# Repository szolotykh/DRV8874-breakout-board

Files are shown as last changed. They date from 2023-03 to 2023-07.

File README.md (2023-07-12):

# Motor Controller DRV8874

The Motor Controller, harnessing the power of the DRV8874 H-bridge motor driver by Texas Instruments, offers a top-of-the-line solution for managing small to large DC motors. This compact yet potent device presents an expansive operating supply voltage range of 4.5V to 37V, assuring adaptability with diverse power inputs. It is capable of delivering a peak current of up to a remarkable 6A, ensuring smooth and efficient motor operations even under strenuous conditions. Armed with advanced safety and protection features including overcurrent, thermal, undervoltage, and even charge pump undervoltage, the motor controller prioritizes your motor's durability and reliable performance. Whether your project involves creating a versatile home appliance, an interactive toy robot, or an advanced servo motor system, this motor controller delivers effortless integration and superior performance, empowering your projects with precision and power.

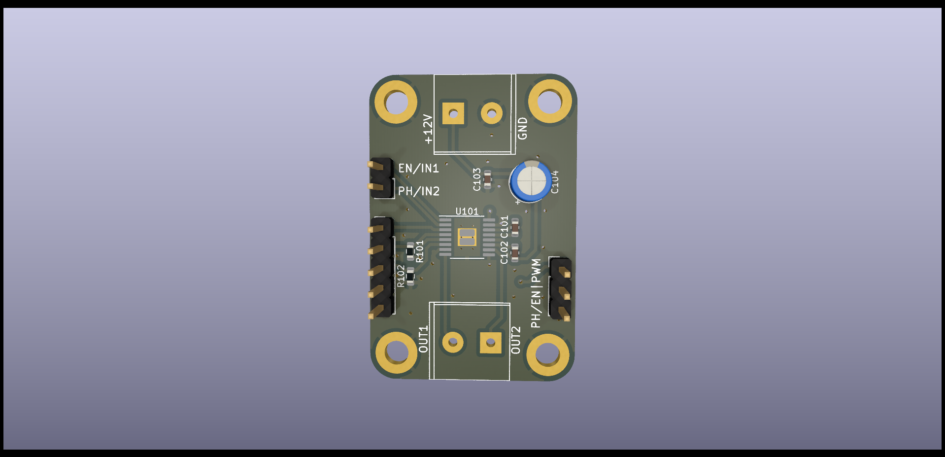
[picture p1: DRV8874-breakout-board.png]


## Features
- PWM control
- PH/EN control
- Motor Voltage 4.5V to 37V
- Peak current 6A
- Current limit 6A
- PWM frequency upto 100 kHz
- 200-mΩ (High-Side + Low-Side)
- Dimensions 27 mm x 40 mm
- Mounting hole diameter 3.2 mm
- Integrated current sensing and regulation
- Undervoltage lockout
- Charge pump undervoltage
- Overcurrent protection
- Thermal shutdown
- Automatic fault recovery
- Fault indicator pin (nFAULT)
Note: For more information refer to DRV8874 datasheet.

## Control Modes

The DRV8874 Breakout Board supports two different control modes: PH/EN and PWM. The PH/EN mode uses the PH and EN pins to control the motor, while the PWM mode uses the IN1 and IN2 pins and PWM signals to control the motor.

To switch between the control modes, you need to change the position of the "PH/EN|PWM" jumper on the board. When the jumper is in the PH/EN position, the board is in PH/EN mode. When the jumper is in the PWM position, the board is in PWM mode.

## Arduino Examples

* [PWM Control](./exampes/PWMControl/PWMControl.ino)
* [PH/EN Control](./exampes/PHENControl/PHENControl.ino)
* [Current Sensing](./exampes/CurrentSensing/CurrentSensing.ino)

## Resources

- [Texas Instruments DRV8874](https://www.ti.com/lit/ds/symlink/drv8874.pdf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)

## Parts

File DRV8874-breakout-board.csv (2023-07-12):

Reference | Value | Footprint | LCSC Part # | Qty
C101 | 22nf | Capacitor_SMD:C_0603_1608Metric | C277528 | 1
C102, C103 | 0.1uf | Capacitor_SMD:C_0603_1608Metric | C14663 | 2
C104 | 47u | Capacitor_THT:CP_Radial_D5.0mm_P2.00mm | In stock | 1
J101, J103 | M0_CONN | VsReality_Footprints:JILN JL126-50002G01 | C394556 | 2
R101 | 10K | Resistor_SMD:R_0603_1608Metric | C116677 | 1
R102 | 1.2K | Resistor_SMD:R_0603_1608Metric | C114605 | 1
R103 |  | Resistor_THT:R_Axial_DIN0204_L3.6mm_D1.6mm_P5.08mm_Horizontal | C114605 | 1
U101 |  | Package_SO:HTSSOP-16-1EP_4.4x5mm_P0.65mm_EP3.4x5mm_Mask2.46x2.31mm_ThermalVias | C1855818 | 1

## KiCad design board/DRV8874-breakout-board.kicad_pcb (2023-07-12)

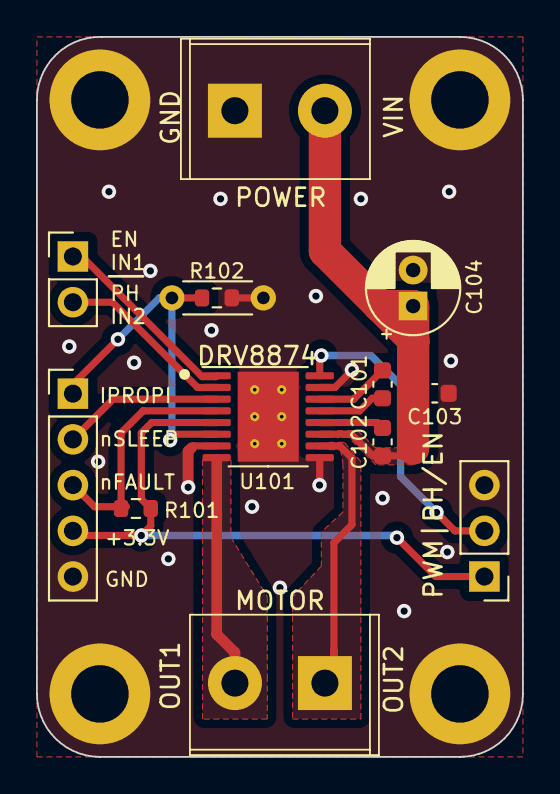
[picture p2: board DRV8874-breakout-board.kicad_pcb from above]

Board: 2 copper layers, 27.0 x 40.0 mm, 17 parts (0 on the bottom side), 14 nets.

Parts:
C101: 22nf; C_0603_1608Metric
C102, C103: 0.1uf; C_0603_1608Metric
C104: 47u; CP_Radial_D5.0mm_P2.00mm
H101, H102, H103, H104: MountingHole; MountingHole_3.2mm_M3_DIN965_Pad
J101, J103: M0_CONN; JILN JL126-50002G01
J102: Conn_01x02_Pin; PinHeader_1x02_P2.54mm_Vertical
J104: Conn_01x06_Pin; PinHeader_1x05_P2.54mm_Vertical
J105: PMODE; PinHeader_1x03_P2.54mm_Vertical
R101: 10K; R_0603_1608Metric
R102: 1.2K; R_0603_1608Metric
R103: R_Axial_DIN0204_L3.6mm_D1.6mm_P5.08mm_Horizontal
U101: HTSSOP-16-1EP_4.4x5mm_P0.65mm_EP3.4x5mm_Mask2.46x2.31mm_The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

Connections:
+3V3: J104.4, J105.1, R101.1, U101.5 (VREF)
GND: C103.1, C104.2, H101.1, H102.1, H103.1, H104.1, J103.1, J104.5, J105.3, R102.2, R103.2, U101.7 (IMODE), U101.9 (PGND), U101.15 (GND), U101.17 (Pad)
IN1: J102.1, U101.1 (EN/IN1)
IN2: J102.2, U101.2 (PH/IN2)
IPROPI: J104.1, R102.1, R103.1, U101.6 (IPROPI)
unnamed: C101.1, U101.13 (CPH)
unnamed: C101.2, U101.14 (CPL)
unnamed: C102.2, U101.12 (VCP)
OUT1: J101.2, U101.8 (OUT1)
OUT2: J101.1, U101.10 (OUT2)
PMODE: J105.2, U101.16 (PMODE)
VMOTORS: C102.1, C103.2, C104.1, J103.2, U101.11 (VM)
nFAULT: J104.3, R101.2, U101.4 (nFAULT)
nSLEEP: J104.2, U101.3 (nSLEEP)

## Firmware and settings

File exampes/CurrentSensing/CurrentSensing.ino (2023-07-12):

/* ----------------------------------------------------------------------
File: CurrentSensing.ino
Author: Sergey Zolotykh
---------------------------------------------------------------------- */
int in1Pin = A1;
int in2Pin = A2;

int nSleep = 13;

const int ipropiPin = A4;

// Set the motor speed to half of the maximum
int motorSpeed = 128;

double Vref = 3.3;
double Aipropi = 0.455;
double Ripropi = 1.2; // 1.2 KOhm
int DacMax = 1024;

void setup() {
  Serial.begin(9600);
  // Enable motor controller
  pinMode(nSleep, OUTPUT);
  // set the motor control pins as outputs
  pinMode(in1Pin, OUTPUT);
  pinMode(in2Pin, OUTPUT);

  digitalWrite(nSleep, HIGH);

  analogWrite(in1Pin, motorSpeed);
  analogWrite(in2Pin, 0);
}

void loop() {
    int avarage = analogRead(ipropiPin); // Read the analog value
    double current = ((double)avarage/DacMax * Vref) / (Ripropi * Aipropi);
    Serial.print(avarage);
    Serial.print(" - ");
    Serial.println(current);
    delay(1000);
}

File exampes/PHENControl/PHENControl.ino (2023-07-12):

/* ----------------------------------------------------------------------
File: PHENControl.ino
Author: Sergey Zolotykh
---------------------------------------------------------------------- */

// Define the motor control pins
int phPin = D1;
int enPin = A1;

void setup() {
    // Set the motor control pins as outputs
    pinMode(phPin, OUTPUT);
    pinMode(enPin, OUTPUT);

    // Set the direction
    digitalWrite(phPin, HIGH);

    // Set the speed to 50%
    analogWrite(enPin, 127);

    // Set the speed to 100%
    analogWrite(enPin, 255);

    // Reverse the direction
    digitalWrite(phPin, LOW);

    // Stop the motor
    analogWrite(enPin, 0);
}

void loop() {
// do nothing
}

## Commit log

2023-03-17 Initial version
    [DRV8874-breakout-board.kicad_pcb, DRV8874-breakout-board.kicad_sch]
2023-03-19 Additional changes
    [DRV8874-breakout-board.kicad_pcb, DRV8874-breakout-board.kicad_sch]
2023-03-22 First release version
    [DRV8874-breakout-board-B_Cu.gbr, DRV8874-breakout-board-B_Mask.gbr, DRV8874-breakout-board-B_Paste.gbr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]
2023-04-11 Added external resistor
    [DRV8874-breakout-board.kicad_pcb, DRV8874-breakout-board.kicad_sch]
2023-04-12 Fixed issue with text
    [DRV8874-breakout-board.kicad_pcb]
2023-04-21 Added trace zones
    [DRV8874-breakout-board.kicad_pcb, DRV8874-breakout-board.kicad_sch]
2023-04-21 Update screw terminal
    [DRV8874-breakout-board.kicad_pcb, DRV8874-breakout-board.kicad_sch]
2023-07-12 Update board files
    [DRV8874-breakout-board-B_Cu.gbr, DRV8874-breakout-board-B_Mask.gbr, DRV8874-breakout-board-B_Paste.gbr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]
2023-07-12 Update arduino examples
